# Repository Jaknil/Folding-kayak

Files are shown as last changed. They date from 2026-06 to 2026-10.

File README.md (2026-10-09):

# Folding-kayak

Build logs and instructions for making your folded origami kayaks from sheet of polypropylene plastic sheets. Original concept invented by [Aslag Guttormsgaard:](https://www.instagram.com/aslagsbrettekajakk/)

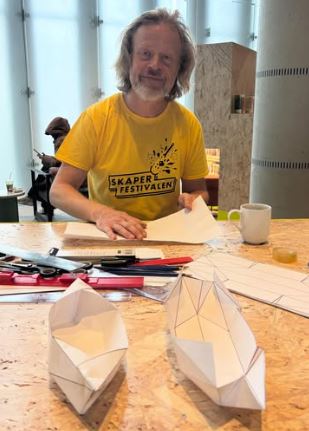
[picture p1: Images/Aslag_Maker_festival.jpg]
Aslag Guttormsgaard at Oslo Maker festival Deichman 2025, image from aslagsbrettekajakk on Instagram
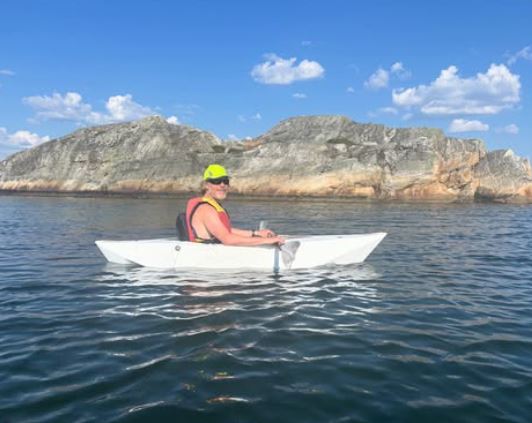
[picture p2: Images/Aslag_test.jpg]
Aslag Guttormsgaard on Koster, image from aslagsbrettekajakk on Instagram


# What is it?

A do it yourself kayak, made from a plastic sheet that is ultralight and packs up to a flat package. Read on to learn how.

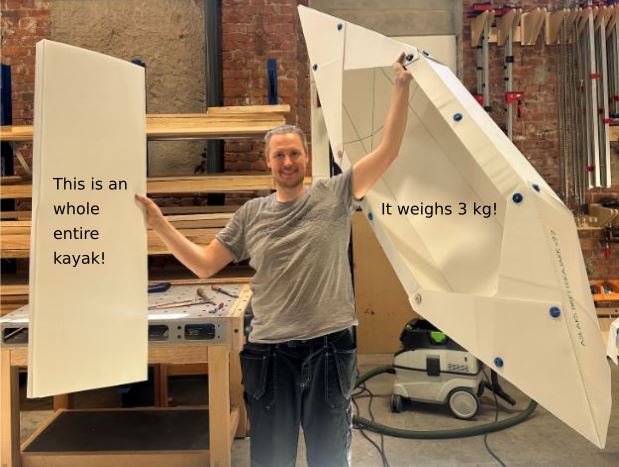
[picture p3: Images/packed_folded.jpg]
Jakob holding a packed and a folded kayak


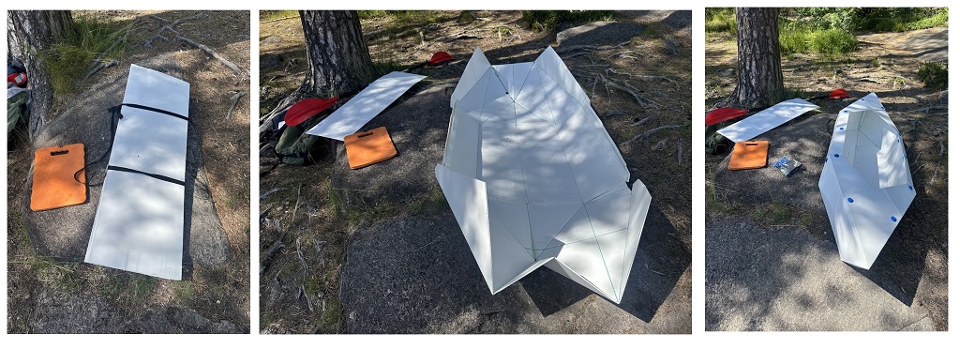
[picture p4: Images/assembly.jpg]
Assembly


It packs up to approximately 1220x500x50mm (left picture) and weighs 3kg total without paddles. Packing up or down took around 15 minutes each for my first time, [the inventor has the record with a 4 min assembly!](https://www.instagram.com/p/DQYdUIIiCEW/)

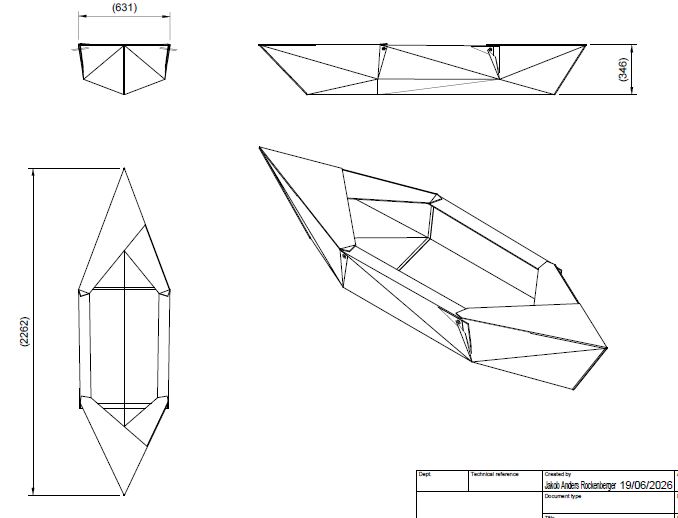
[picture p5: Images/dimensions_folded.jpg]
Dimensions folded


# But does it work?

Yes! We have made five thus far and tested them. The different versions have different quirks and fixes, see version log for details.

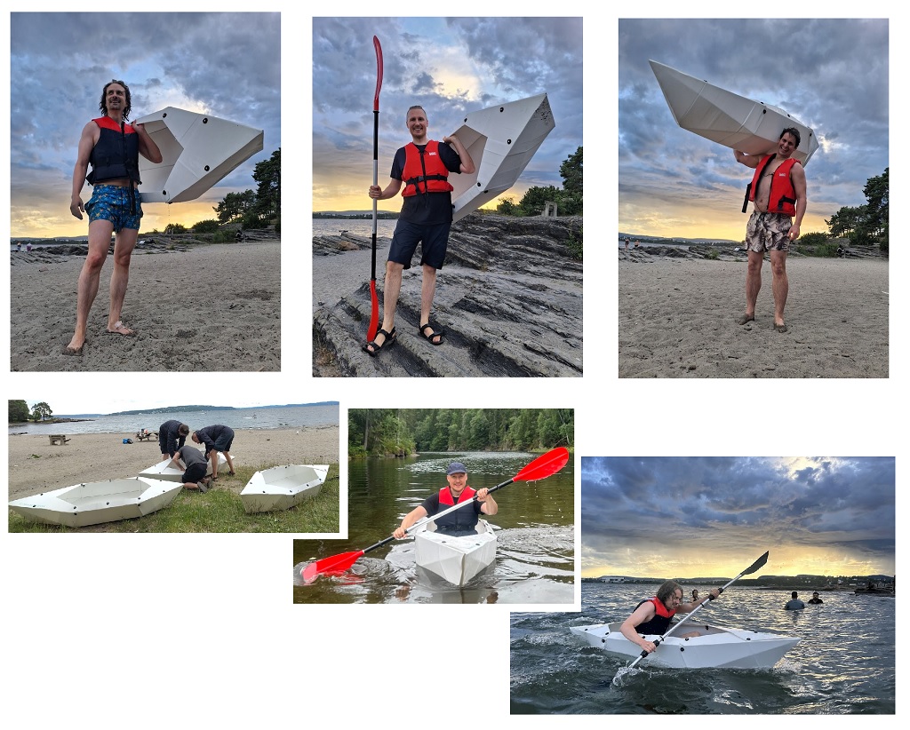
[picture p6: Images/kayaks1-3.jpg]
Testing the first three kayaks


Tests at Paradisbukta and Østmarka, Oslo 2026.

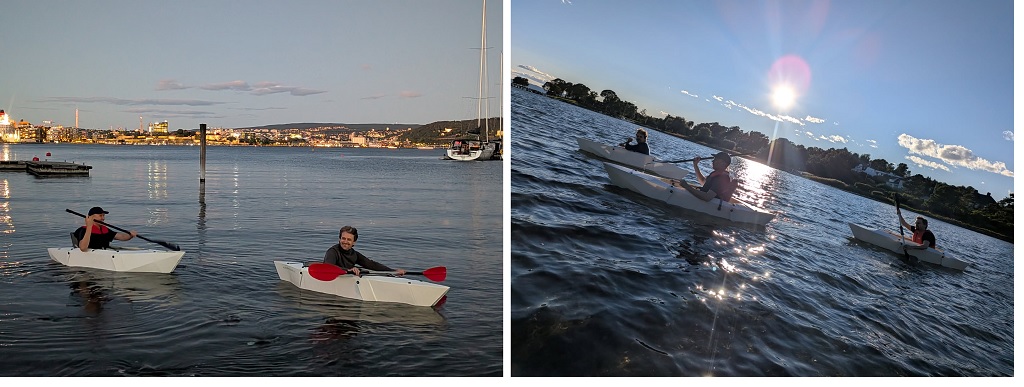
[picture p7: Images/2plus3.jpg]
Herbern trip


Restaurant trip to Lille Herbern, Oslo 2026.

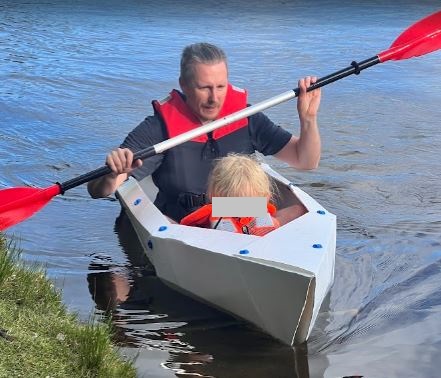
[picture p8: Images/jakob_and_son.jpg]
Father and son


1-2 kids on board as ballast has been found to improve stablity

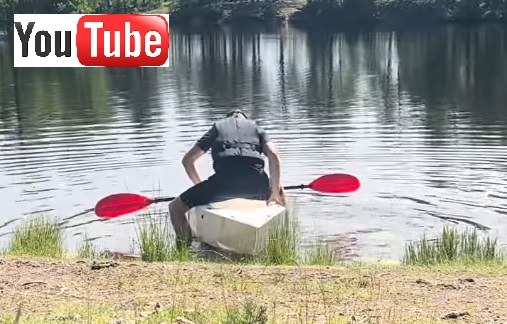
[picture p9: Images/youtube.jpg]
(https://youtu.be/oQs99TTAEPQ?si=FxAfOIfxH4dqbu4J)


[First test video on Youtube](https://youtu.be/oQs99TTAEPQ?si=FxAfOIfxH4dqbu4J)

## Who? Where?
We are a group of five Makers based in Oslo Norway attempting to make, improve and share Aslags fantastic kayak design! 

We are working out of the shared workshop [Fellesverkstedet](https://www.fellesverkstedet.no/) and they have been incredibly helpful in procuring the materials needed for the project. 

We are also making use of Norways biggest Makerspace: [Bitraf](https://bitraf.no/), for 3D -printing the fasteners.

### Production log 

We have made make 5 kayaks out of 8 sheets of polypropylene. Updated 09.102.2026

| Sheet | Use | Status |
| ----- | --- | --- |
| 1 |Seat for Kayak 1 + test| Done |
| 2 |Kayak 1 v2.2| Done |
| 3 |Kayak 2 v2.2| Done |
| 4 |Kayak 3 v2.2| Done |
| 5 |Kayak 4 v2.3| Done |
| 6 |Kayak 5 v2.3| Done |
| 7 |Seats for 2-3 v2.3| Done |
| 8 |Seats for 4-5 v2.3| Done |
| 9 | Spare| Planned autocrease experiment  |

Sheet 9 will be used to test the [autocreaser](autocreaser.md) 

## How to make folded kayaks

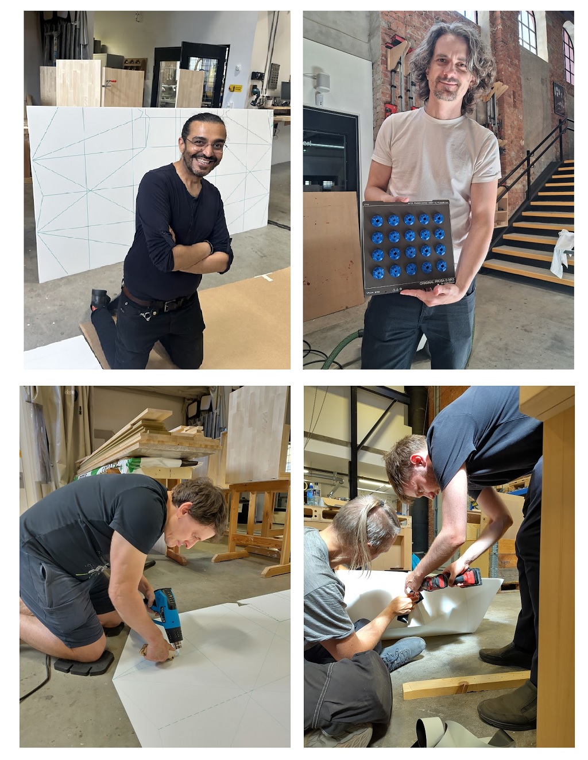
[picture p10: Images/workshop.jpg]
The crew working on version 2.2


### Bill of materials, per kayak:
- 1.5pcs of 2440mm x 1220mm fluted / internally corrugated polypropylene sheet - 4mm thickness 700g/m^2 - 1.5pcs / Kayakk ([Antalis supplier](https://www.antalis.no/eshop/medier-og-utstyr-for-visuell-kommunikasjon/plater/kanalplast-pp-pdp-hq08108/sku-694530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))
- 14pcs of M6 hex head screws 30mm length 
- 14pcs of M6 nuts
- Filament for 3D printing 28 lock washers (we used PLA) 
- Gaffa tape for temporary assembly

### Tools:
- 3D-printer for printing lock washers
- Exacto knife for cutting plastic
- A pen and a ruler or a large CNC for marking the sheets
- Hot air gun, preferably one that can be set to 150C
- Hand held roller, Ø5-10mm wide ca Ø30mm diameter. Can be laser cut, 3D-printed or made from scrap. [Rihno files](Lasercut-creasing-tool/CreasingToolv1.3dm)
- Handheld drill and a Ø6-7mm drill bit

### Methodology

Preparations:
1. 3D-Print all the lock washers (print a test one first)
2. Push the screws and nuts into the 3D-prints 

Making the Kayaks:
1. Find a large open space to work in. 4m x 2m minimum.
1. Mark where you want to cut and fold your sheet
1. [Cut the small pieces away](Images/cut.jpg)
2. [Heat the plastic locally to 150C using the hot air gun and](Images/crease.jpg)
3. [Create creases along the lines using a roller](Images/crease.jpg) 
4. Use a board or something stiff under the sheet when you first it, to help establish straight folds
5. [Youtube video: Shape the kayak and fix it in place using gaffa tape](https://youtube.com/shorts/2akg2EgOliQ)
6. Drill the holes for the screws
8. Use the screws and nuts with the 3D printed lock washers to assemble the whole kayak

# Research

- A sheet metal model was developed, see [tests for establishing k-value and new approximated sheetmetal model](sheet_metal_theory.md)
- An [auto-creasing tool](autocreaser.md) is being developed.
- Test alternative sheets designs to the channeled one

## Alternative sheet test

- [Akyprint smooth 3.3mm 900g/m from VINK](https://vink.no/media/import/NO_Akyprint_Brosjyre.pdf), works great in small scale test!

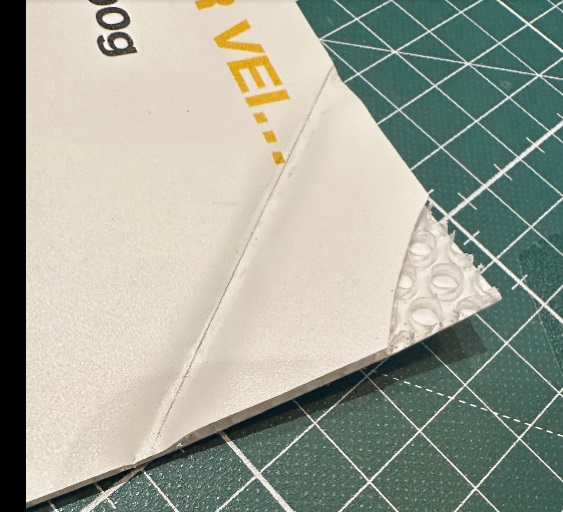
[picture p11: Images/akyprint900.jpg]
Standard heat crease and demo cut


[See autocreaser for more tests](autocreaser.md)

## Todo

- Test [autocreaser](autocreaser.md) in CNC
- Test out low seats with backs like [Falkeberg Ground Chair](./Images/ground_chair.JPG)
- Develop version 3.0 of the folding kayak 

## Version 3 - Under development

Change log
- Introduces more angles to the first pack up lines, makes a rounder more complex shape. 

Next step:
- Make new paper tests 

Only tested in paper.

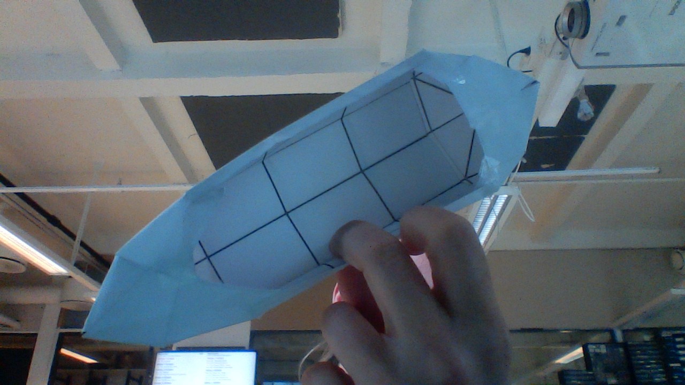
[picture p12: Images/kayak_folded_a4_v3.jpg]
Version 3 kayak


- [PDF drawing for A4 models](Drawings/V3_1Oct_double_top.pdf)

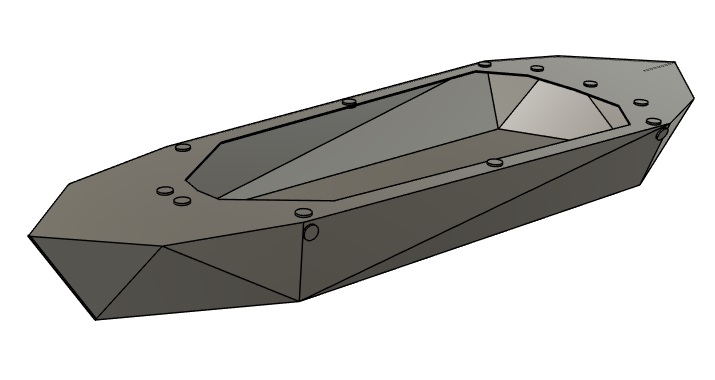
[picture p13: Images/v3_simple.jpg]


- [3D-model, web view](https://a360.co/4iS6Kz8) Including a comparison with v2 and a righting arm analysis setup

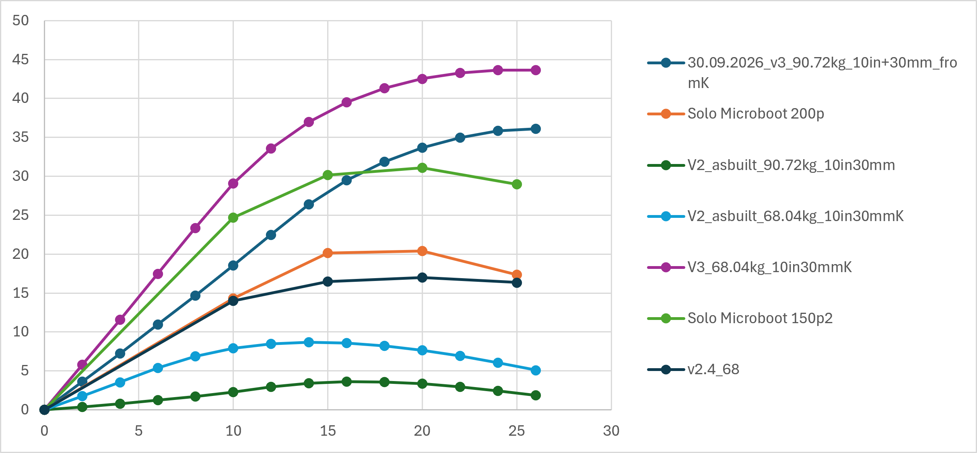
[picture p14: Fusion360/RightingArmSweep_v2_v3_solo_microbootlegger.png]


Righting arm vs Heel angle plot for different loads. Centre of gravity 254mm (10in = standard pilot assumption) + 30mm (assumed seat height) above keel.

- [Graph data CSV](Fusion360/TestData_v3_comp.csv)
- [Graph data Excel](Fusion360/RightingArmSweep_cleaned_plotted.xlsx)
- [Kayak stability therory](https://guillemot-kayaks.com/kayak-stability)
- [Solo Microbootlegger kayak](https://guillemot-kayaks.com/catalog/strip-built/recreational-kayak-solo/solo-microbootlegger) used as comparision

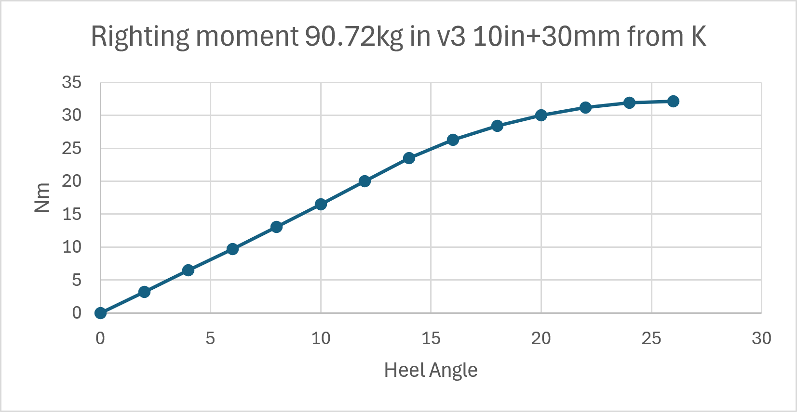
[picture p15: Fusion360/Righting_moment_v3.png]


- [DXF pattern](Drawings/Simple_pattern_v3_top_lines.dxf)

# Version history and test log

## Version 2.4

Not tested on paper, looks ok in old cad model that I don't trust completely.

[DXF for autocrease](Drawings/dxf-main_v2.4.dxf)

Remember to add double lines 6.7mm c-c for double folds!

Double crease all double folds:
- All pack up lines except the double ones in the middle
- All backside lines (4 flaps on sides and 2 on the points)
- Consider double folding armrests
- If time, test wider armrests

### Change log 
- The front is shorter to accomodate better pack up lines, also increases stability
- It's 50mm wider and 25mm lower than 2.3, making it more stable.

## Version 2.3

We made one or two of this main body but had seat inlays from v2.2, so no full v2.3 exist.

 These tweaks aim to stiffen the kayak further and avoid the innvards collapses. 
 
 - This update tries out several things, possibly overcomplicating the design. Some of these fixes might be enough on their own. 
 
### Change log 

- Extend the seat-inlay to use half a full sheet of polypropylene 1220X1220 = more bending, but creates lots more dimentions
- Move all the "pack up lines" to intersect with other lines. 
- Slope the cockpit sides innward to make the bends sharper in the nose and rear. This means cutting more from the corners, how much? Freehand? possibly not needed? Can we achieve the same thing some other way?

### Drawings

PDF in work!

[JPG Seat v2.3](./Drawings/seat_v2.3_tested.jpg)

[PDF Brettekajakk v2.3 pack_up lines only](./Drawings/Brettekajakk_pack_up_lines_v2.3.pdf)

[DXF seat v2.3](./Router-plot-DXF/Seat_v2.3_DXF.dxf) OBS! Error! one dimension is inncorrect. See JPG for correction

[DXF kayak main file v2.3](./Router-plot-DXF/Brettekayak_JR_v2.3.dxf)

### 3D-prints
- [1pcs-Lock-washers-folding-kayak-M6-Screw-holder.3mf](3D-print-3MF/1pcs-Lock-washers-folding-kayak-M6-Screw-holder.3mf)
- [28pcs-Lock-washers-folding-kayak-M6-Screw-holder.3mf](3D-print-3MF/28pcs-Lock-washers-folding-kayak-M6-Screw-holder.3mf)

## Version 2.25

This is using a v2.2 kayak main body and a v2.3 seat inlay.

### Test results and impressions

- The seat inlay v2.3 was a success! It stopped most of the inversions that v.2.2 suffered from. We don't know if this more complicated seat is strictly neccessary for version 2.3 kayaks but it gives more strength than 2.2 so it doesn't hurt.
- The ergonomics is still somewhat lacking. A backrest would be very nice for any longer trips. We have not tested the beach chair solution yet.
- The sides are rather high and wide, they can be pulled in front of the pilot to give better room to paddle. 
- The pilot has to sit almost in the very middle of the kayak with their feet in the tip for the kayak to float level in the water. There is room for improvement! We consider a more almond shaped design for version 3.0 with a wider back and narrow front. 
- [We have taped up the open edges of the sheet with silver-tape.](Images/taped.jpg) It can give it around 10 liters of trapped air for lift in an emergency and reduce cuts and scrapes. Especially on the sides of the cockpit.

## Version 2.2

### Test results and impressions

June 22 2026 - Jakob Rockenberger at Vesletjern

 It handles OK. Not fast not very rank or very stable. Tracks fine, not very fast. Survived some banging and grinding on rocks. Since it lacks sealed air chambers it's not something I'd risk the open seas with, but prefect for exploring a lake or a creek where you can swim to shore if you need it. The main advantage is that you can easily pack it up and take a bus home afterwards. I weigh 75kg and paddled easily around a small lake together with my 5 year old! 
 
 I sat on a foam mat with a rolled up towel underneath to let the boat keep the V shape in the bottom. We can possibly make a triangle from leftover material that we can use instead if we have enough. 

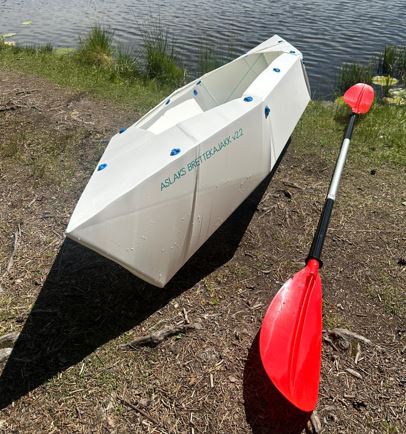
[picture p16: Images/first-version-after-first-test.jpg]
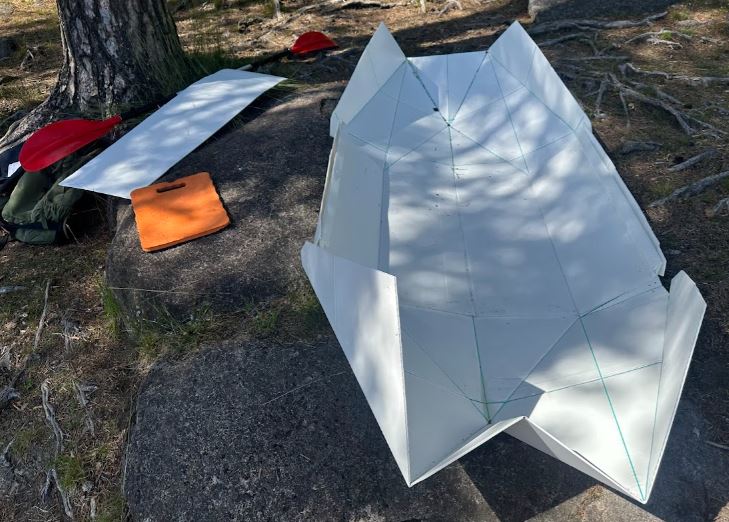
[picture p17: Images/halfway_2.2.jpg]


#### Inversions

- The kayak experienced some innvards local "collapses" of the shape of the Kayak, surfaces that should be convex became concave, when they were pushed in by the water-pressure. This happend in the bottom area under my calves and behind me from both sides. 
- Note that the kayak didn't become unsafe when this happened! When the bottom front inverted, the sideways stabiliy increased as well as the drag. I didn't notice the rear inverting until later, but I assume I lost some boyancy, forcing me to sit more to the front
- I think the reasons was the "pack up" folds, in this version they didn't intersect existing geometry. This can easily be changed in next version.
- Two more kayaks has already been creased with these unfortunate "pack up" folds, and we want to finish them regardless.
- Several potential fixes will be tested in version 2.3. 

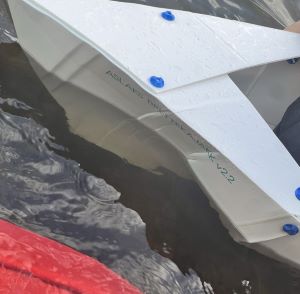
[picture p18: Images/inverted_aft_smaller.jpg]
Aft inversion


### Change log and notes

- The drawings now include previously missing and corrected dimesions for how much to cut off the corners.
- Bend lines for packing up (missing from the PDF drawing) are placed such a way in the DXF that it folds nice and small, around 400mm wide package.
- The bend lines for packing up appear to make it weaker. Consider moving them to natural intersection-points. 
- Was assembled and tested with vertical sides to the cockpit, it is possible that it would be stronger if they were curved in a bit. Intended in v2 original design?

### Drawings 

This is the drawing for our version 2.3. based on a model recreated in Fusion360 by Jakob from Aslags drawings. 

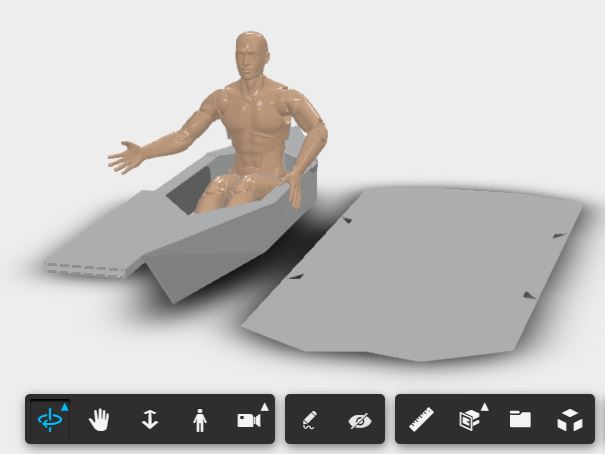
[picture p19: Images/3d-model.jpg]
Interactive 3D-model of the v2.2 kayakk (https://a360.co/4fWsus3)


[*Interactive 3d-model of the kayakk*](https://a360.co/4fWsus3)

[PDF Drawing for version 2.2, without "pack up lines"](./Drawings/Drawing_v2.2.pdf)

[DXF version, with "pack up bend lines"](./Router-plot-DXF/Brettekayak_JR_v2.2.dxf)

## Folding Kayak Aslagstyle - Brettekajakk Aslagstyle v1.0 and V2.0
Invented by [Aslag Guttormsgaard](https://www.instagram.com/aslagsbrettekajakk/) and shared with the public at [Oslo Skaperfestival 25. - 26. oktober 2025](https://deichman.no/aktuelt/oslo-skaperfestival-2025_D67nCl3o7T) ([Alt. link](https://skaperfestivalen.no/)). Attendies could fold their own mini kayaks from printouts on A4 paper. Aslag exibited his model 1 and 2 at the festival.

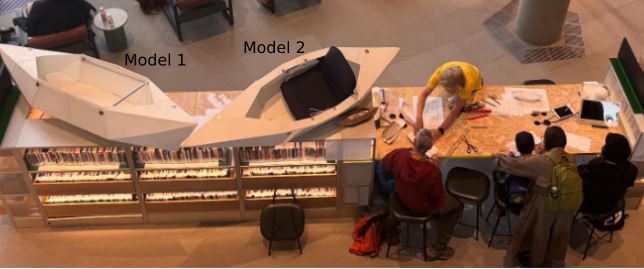
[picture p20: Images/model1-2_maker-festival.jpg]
Model 1 and 2 at the Oslo Maker festival in 2025


### Drawings 

#### Version 2.0 

This is the drawing for version 2.0. Changes from the previous version is that it has the added railing to rest your hands on. Don't mind that the text in the drawing says model 3.

[Drawing for version 2.0](./Drawings/Aslag_Kajakk_modell_2.pdf) "MODELL 3"

#### Version 1.0 

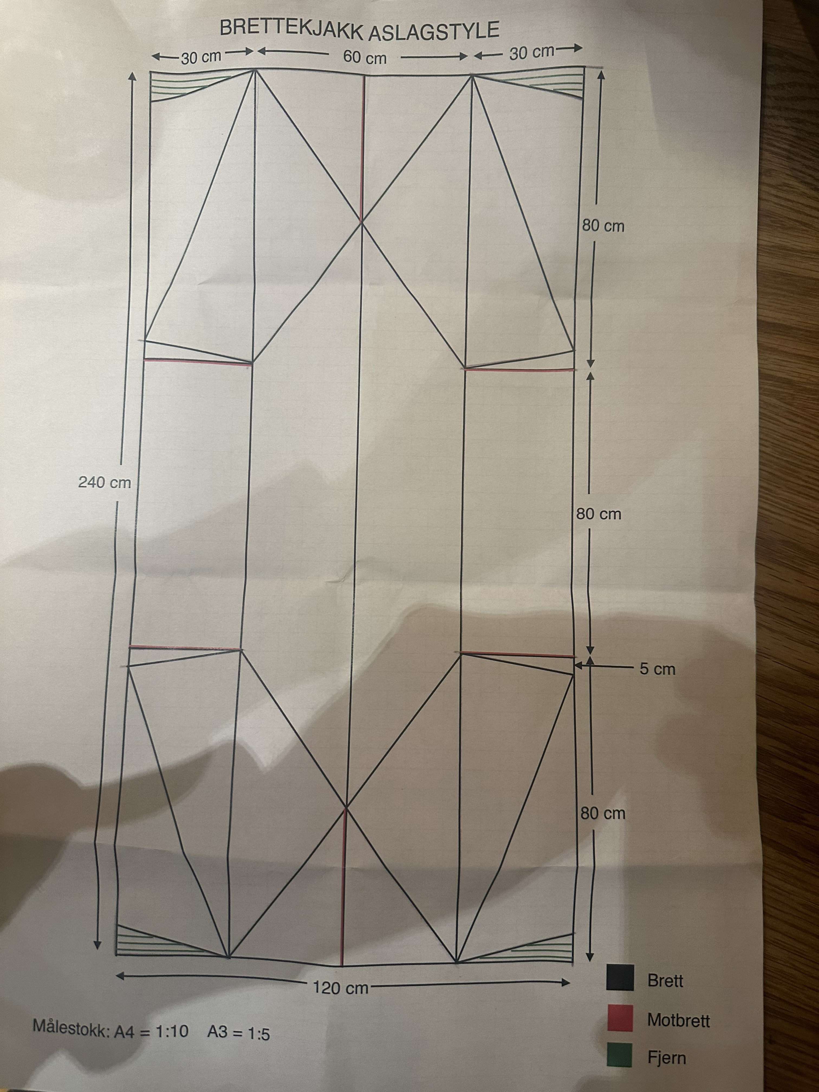
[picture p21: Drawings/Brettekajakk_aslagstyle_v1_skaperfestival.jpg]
Paper handout of version 1.0 from Oslo Maker Festival


Paper handout of version 1.0 from Oslo Maker Festival

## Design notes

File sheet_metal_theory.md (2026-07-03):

# Sheet metal approximation of corrugated plastic sheet in Fusion360

### Motivation
We wanted a more robust way to quickly visualise and generate "correct enough" drawings for new designs of the [folding kayaks.](./README.md)

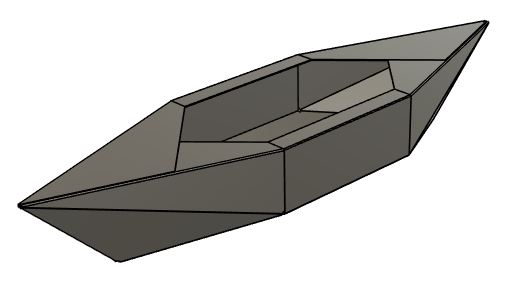
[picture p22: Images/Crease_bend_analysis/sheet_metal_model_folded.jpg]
Sheet metal model of kayak


[*Link to Sheet metal model of kayak in Fusion 360*](https://a360.co/3T9g3j9)

### Results

Our investigations indicate that these were good enough values:

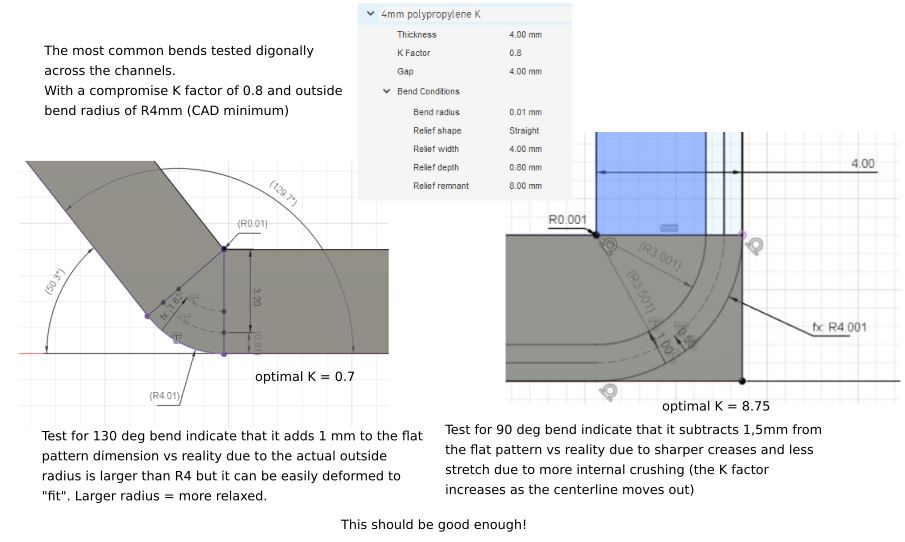
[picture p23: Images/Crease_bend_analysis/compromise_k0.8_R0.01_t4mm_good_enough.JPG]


* K factor = 0.8
* Internal radius = 0.01
* Material thickness = 4
* External radius = 4.01

### Modeling stategy

1. Make 2D sketches defining all critical corners of a quarter of your kayak.
2. Patch them to a surface model, stitch together
3. Make a relief cut at all bend intersections. Revolve a half circle to cut with a sphere.
3. Add the internal radius to all bends
4. Thicken to a solid model
5. Convert the solid model to Sheet metal
6. Unfold and all bends, this adds them to the sheet metal model
7. Add and trim so that the unfolded model respects the sheet boundary
8. Refold
7. Generate flat pattern

Notes:

* Fusion doesn't like the 0.01 internal radius. A larger internal radius = more stable model, but will be less accurate.
* Break down the kayak into quarters for a more stable model. You can extrapolate the last bits.

## Folds to Bends theory

We know that the plastic sheet does not bend as a metal sheet does. The aim here is to find values that take us close enough.

### Metal sheet bending theory:

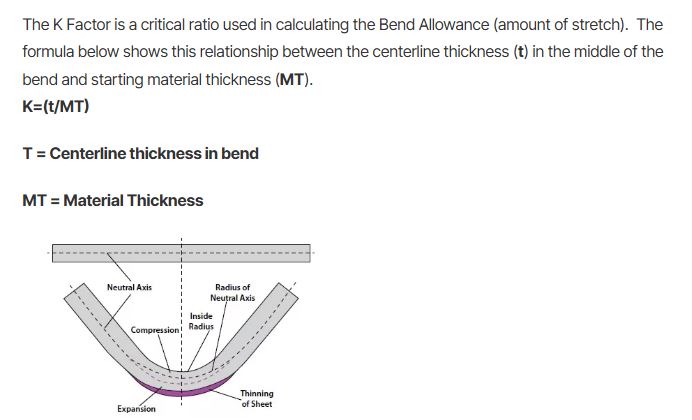
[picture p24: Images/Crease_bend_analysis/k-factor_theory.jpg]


[Image from sendcutsend.com](https://sendcutsend.com/blog/what-is-k-factor-in-bending-terminology/).

### Plastic sheet bending experiments

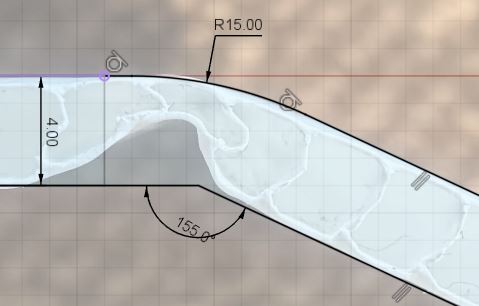
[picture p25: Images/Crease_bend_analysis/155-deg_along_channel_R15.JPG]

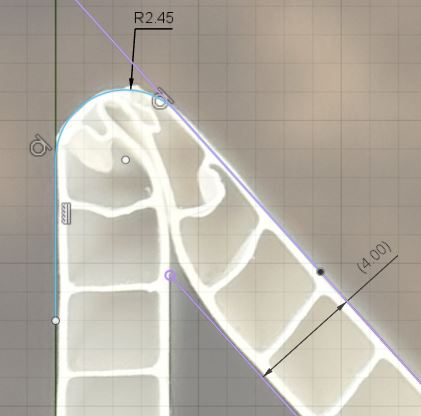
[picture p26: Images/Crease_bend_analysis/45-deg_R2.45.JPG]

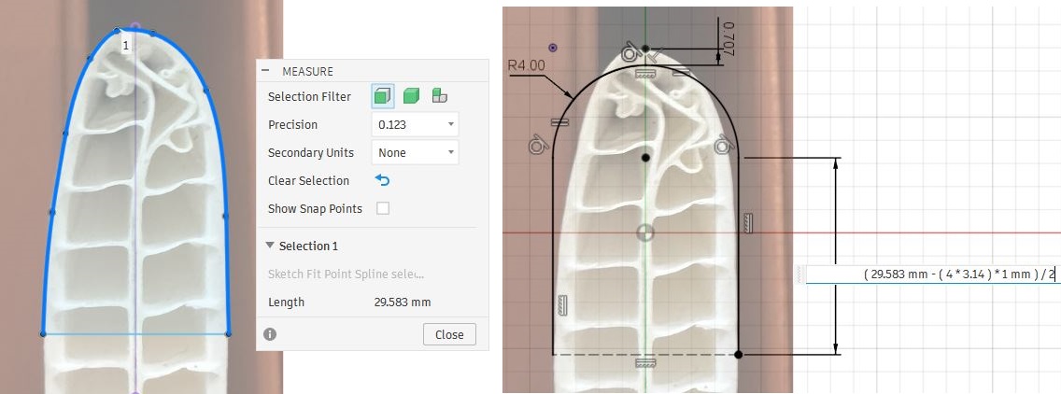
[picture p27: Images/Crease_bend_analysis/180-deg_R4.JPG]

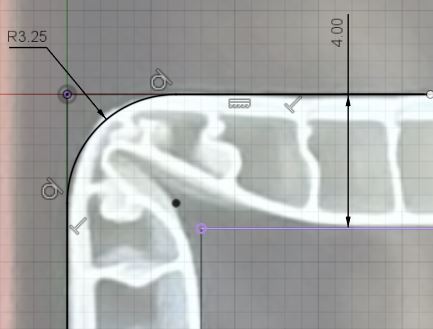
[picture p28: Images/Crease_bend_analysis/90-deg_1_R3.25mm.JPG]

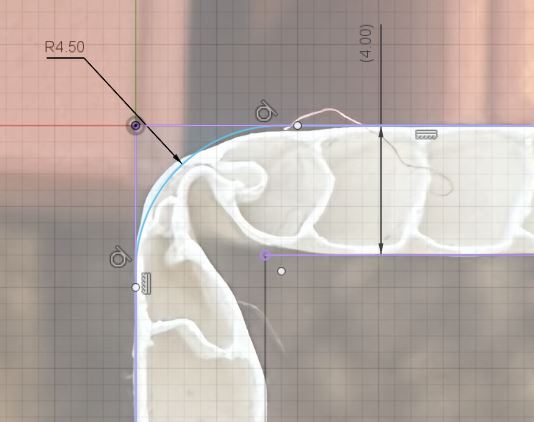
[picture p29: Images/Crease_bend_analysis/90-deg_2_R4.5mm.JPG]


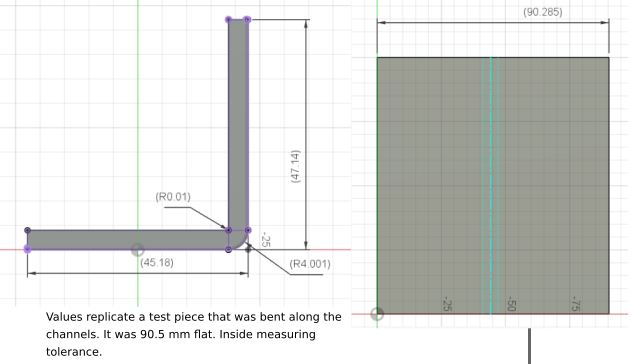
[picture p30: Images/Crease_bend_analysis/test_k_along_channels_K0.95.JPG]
Along channels

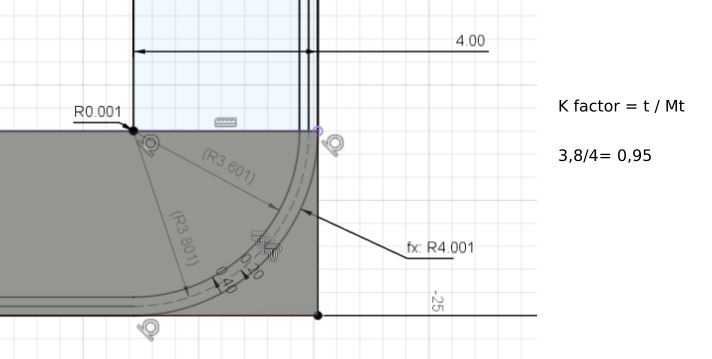
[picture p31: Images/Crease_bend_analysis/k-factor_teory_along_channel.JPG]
Along channels


Bends along the channel should use even higher k factors. Here is a test which indicate k factor =0,95 would worsk for 90 deg bends made along the channels.

#### Observations and conclusions

* Sharper folds = sharper outside radius. Past the point of what is possible to simulate with sheet metal. Meaning we will use the smallest possible inside radius to get as close as we can.
* The K-factor varies with how deep the inside layer crushes into the fold, which is dependent on fold sharpness and channel angle. In the end I had to pick something represenatative.
* Further testing, to be scientific, would be showing "the negative" what happens when the k-faktor/radius is wrong, how bad does it get?
* But this should be enough to move forward with.

### Material properties

The kayaks are built from thin sheets of polypropylene. 

- 4 mm thick plates
- Channels with square cross-sections
- Approximate 0.2mm actual material thickness around and between channels

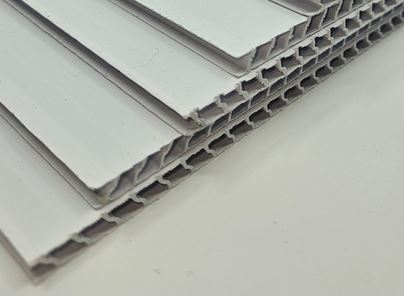
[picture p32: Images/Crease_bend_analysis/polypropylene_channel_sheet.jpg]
Plates (https://www.antalis.no/eshop/medier-og-utstyr-for-visuell-kommunikasjon/plater/kanalplast/kanalplast-pp/pdp-hq08108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)


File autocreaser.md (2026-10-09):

# Autocreaser for folding kayaks

The goal is to be able to use a large CNC machine to automate the creasing of polypropylene sheets when [folding kayaks.](./README.md)

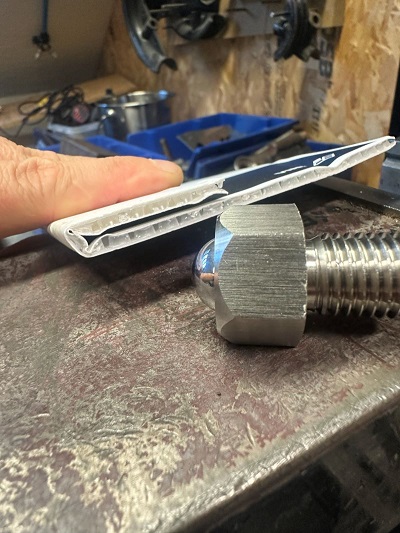
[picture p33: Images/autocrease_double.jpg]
Successful autocrease test, linear 1 axis


Successfull test at [Bitraf](https://bitraf.no/)!

Sheet used: [Akyprint smooth 3.3mm 900g/m from VINK](https://vink.no/media/import/NO_Akyprint_Brosjyre.pdf) with a Ø16mm free rolling ball driven at a fixed height, no heat needed.

Verified double crease line center-center spacing 6.7mm with a 3.3 mm thich sheet. Gives better result than the picture above.

[Youtube short, autocrease test](https://youtube.com/shorts/zlMBDUQS9Cw)

## BOM
- Adapter for creasing ball [Fusion360](https://a360.co/4yF22JU) or [STL-file for printing](3D-print-STL/Adapter.stl)

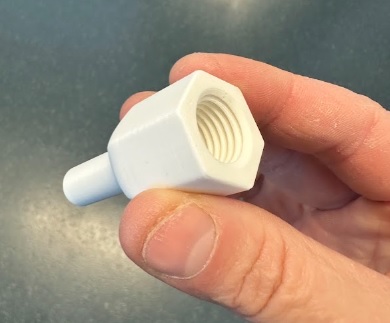
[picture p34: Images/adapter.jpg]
Adapter


The 3D-printed Ø12mm adapter can act as a break-away if we have ha catastrophic collison.

- Conveyor Ball Roller QB312, M16 from [Aliexpress](https://www.aliexpress.com/item/1005005415776359.html)

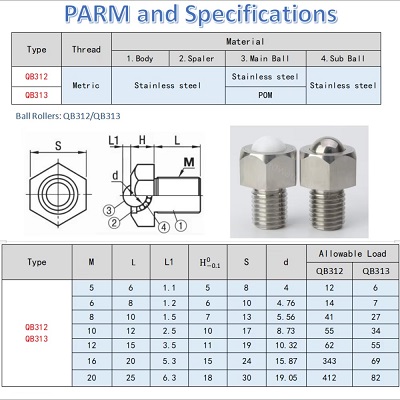
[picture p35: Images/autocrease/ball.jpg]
ball size


## Working principle 

- Mount Ø16mm ball with Ø12mm adapter in spindle collet on shopbot CNC
- Fix the sheet with tape
- Adjust the Z-offset to control the pressure on the sheet
- Crease one side at a time

## First prototype

The spring pin was not smooth enought when exposed to sideways forces.

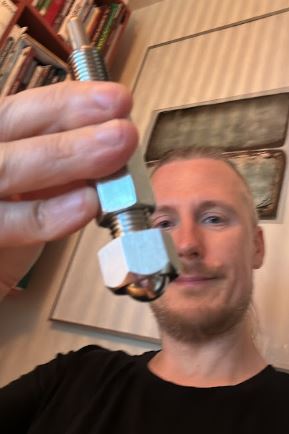
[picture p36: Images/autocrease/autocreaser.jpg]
First prototype


- Ø8mm Steel spring pin QB515-SH, M16 from [Aliexpress](https://www.aliexpress.com/item/1005006329455989.html)

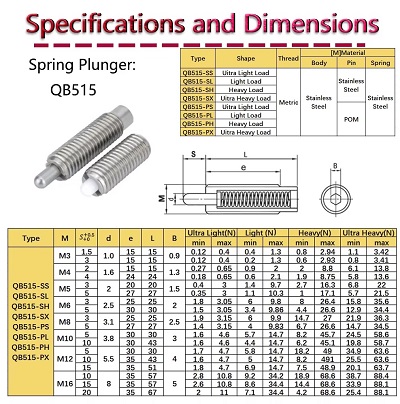
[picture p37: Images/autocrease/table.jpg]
Spring pin force


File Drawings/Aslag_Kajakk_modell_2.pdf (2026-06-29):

## MODELL 3 Inneplate 80x 106

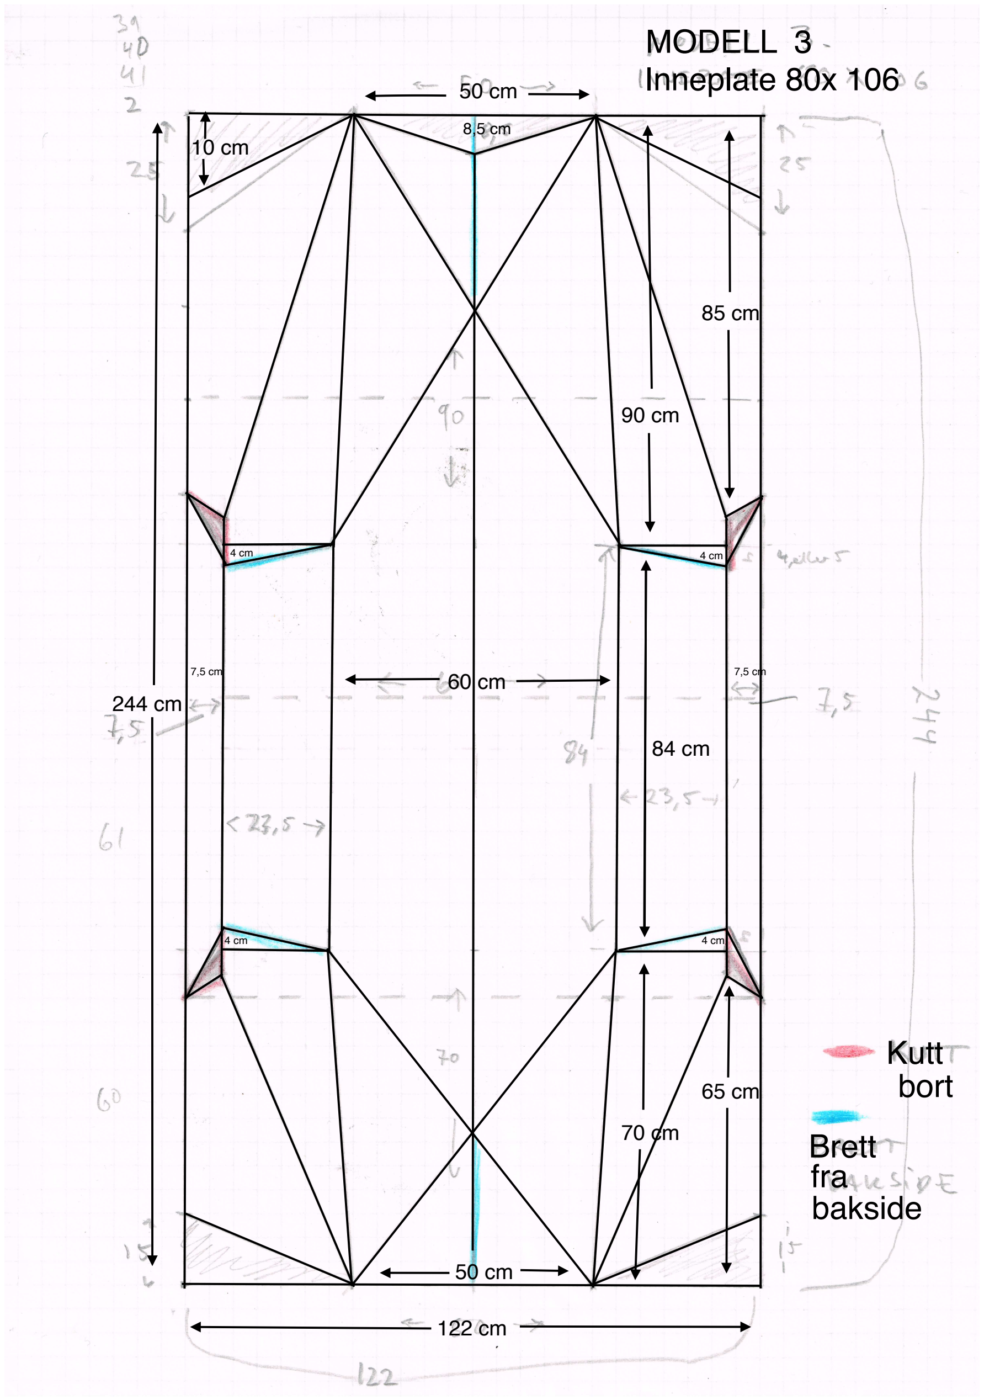
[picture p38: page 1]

84 cm

244 cm

122 cm

## Kutt

50 cm

50 cm

## Brett

7,5 cm

## fra

70 cm

90 cm

4 cm | 4 cm

65 cm

85 cm

## bort

4 cm | 4 cm

7,5 cm

8,5 cm

## bakside

60 cm

10 cm

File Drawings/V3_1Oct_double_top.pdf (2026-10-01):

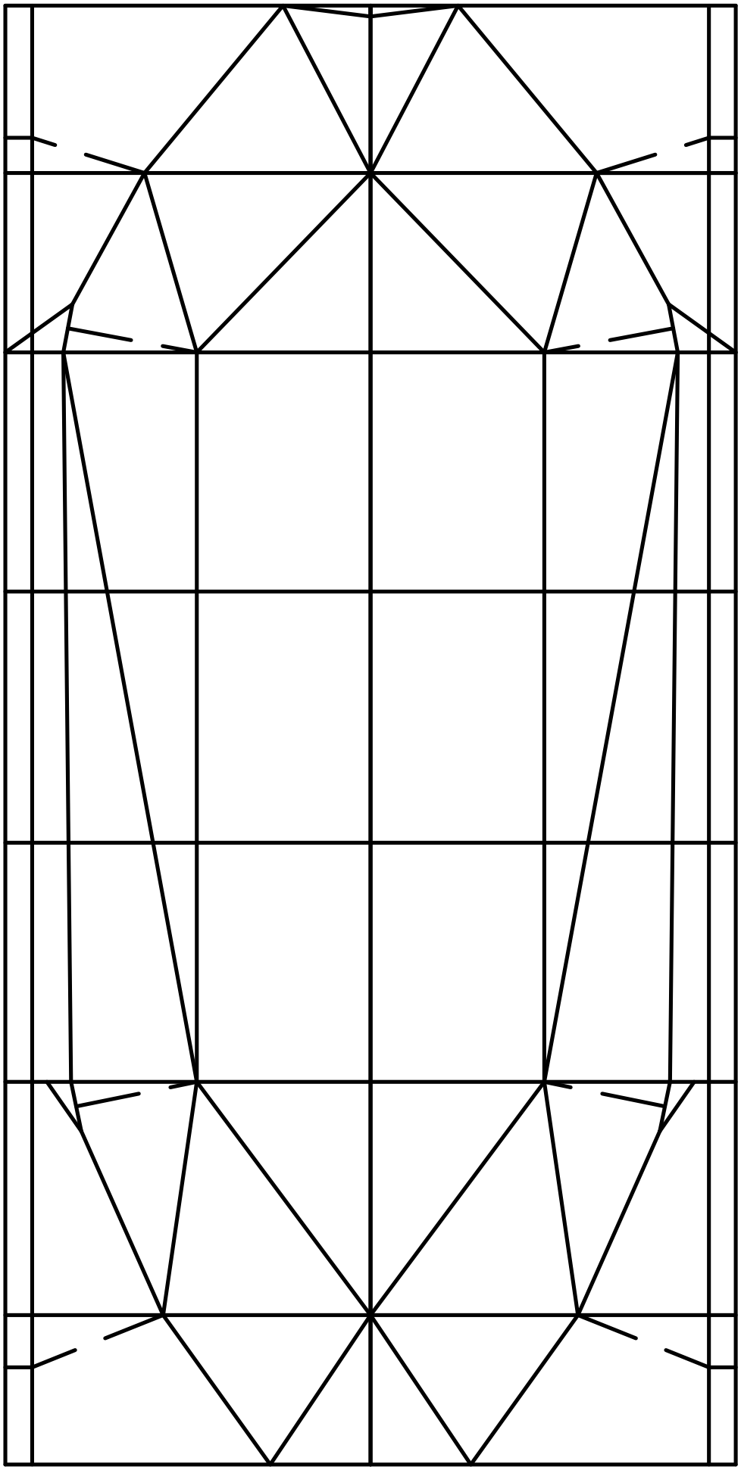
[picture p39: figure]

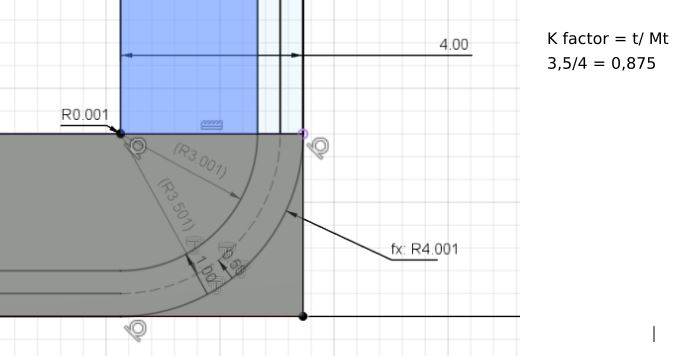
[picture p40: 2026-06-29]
Images/Crease_bend_analysis/k factor - diag alternative_channel-theory_k0.875.JPG

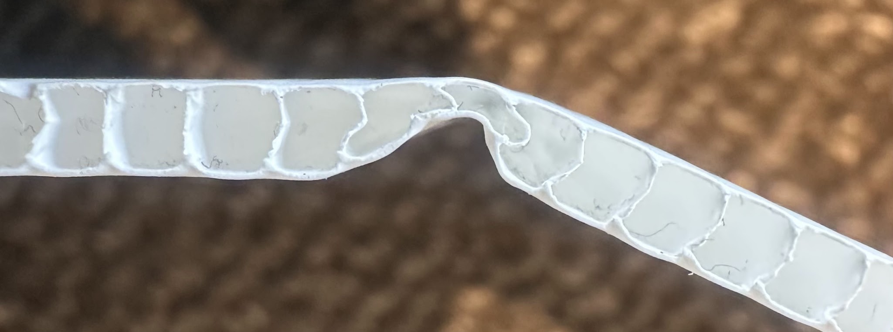
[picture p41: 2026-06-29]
Images/Crease_bend_analysis/155-deg_1.jpg

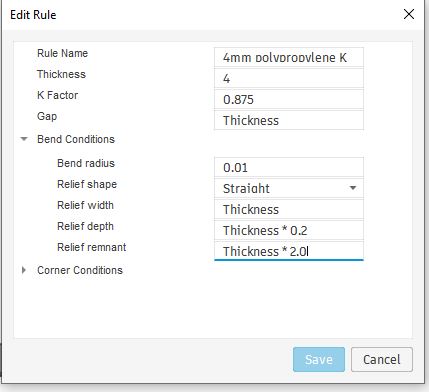
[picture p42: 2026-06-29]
Images/Crease_bend_analysis/k-factor-diag_alt-settings_window_k0.875.JPG

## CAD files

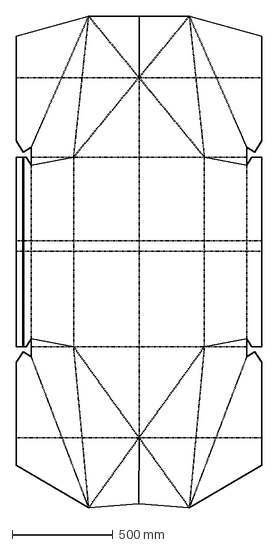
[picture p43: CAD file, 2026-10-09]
Drawings/dxf-main_v2.4_railing.dxf
1220.0 x 2440.0 mm

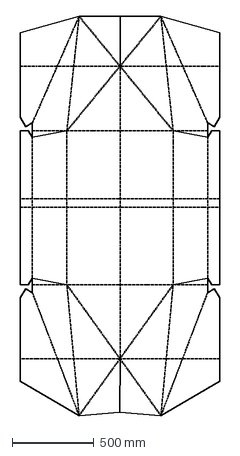
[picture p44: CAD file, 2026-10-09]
Drawings/dxf-main_v2.4.dxf
1220.0 x 2440.0 mm

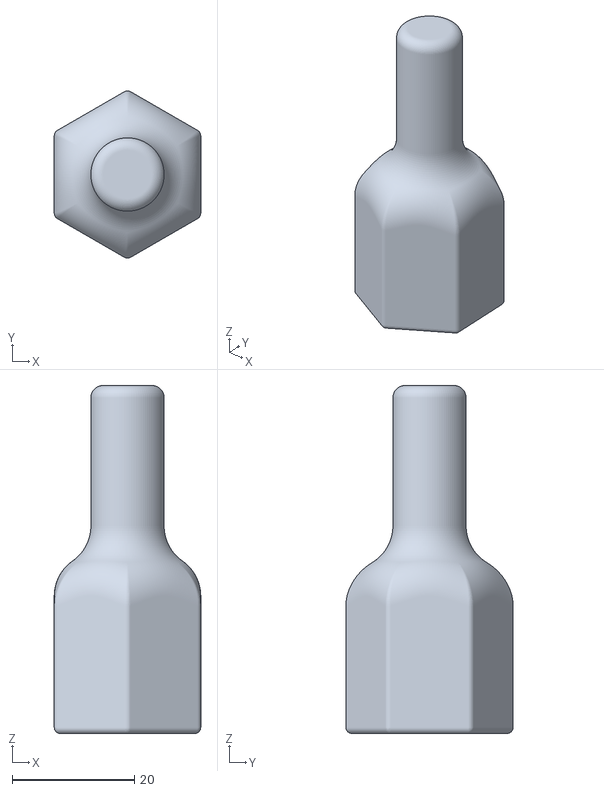
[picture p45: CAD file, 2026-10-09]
3D-print-STL/Adapter.stl
24.0 x 27.4 x 57.0

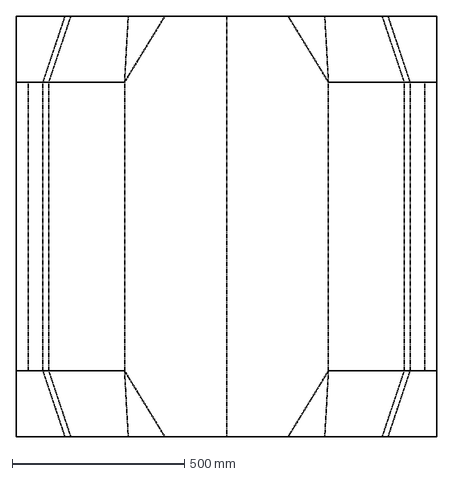
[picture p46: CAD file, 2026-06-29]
Router-plot-DXF/Seat_v2.3_DXF.dxf
1220.0 x 1220.0 mm

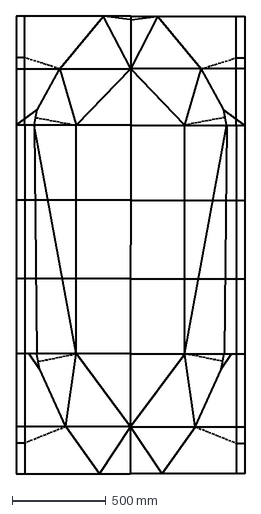
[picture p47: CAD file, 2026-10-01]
Drawings/Simple_pattern_v3_top_lines.dxf
1220.0 x 2440.0 mm

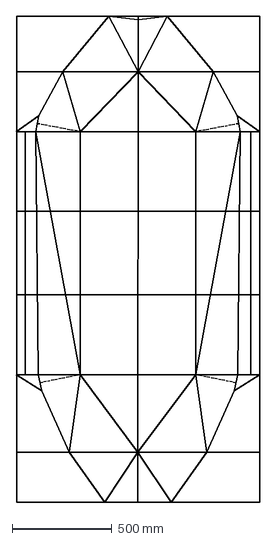
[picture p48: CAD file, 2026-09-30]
Drawings/#Simple_pattern_v3_both_sides.dxf
1220.0 x 2440.0 mm

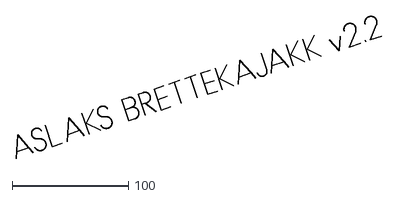
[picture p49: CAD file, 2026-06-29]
Router-plot-DXF/Marker plot - side2 - name.dxf
314.9 x 122.6

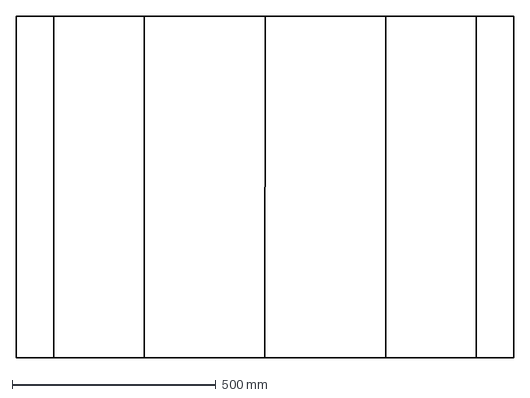
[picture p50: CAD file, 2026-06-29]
Router-plot-DXF/DXF_Seat_reinforce_JR_v2.2.dxf
1220.0 x 838.0 mm

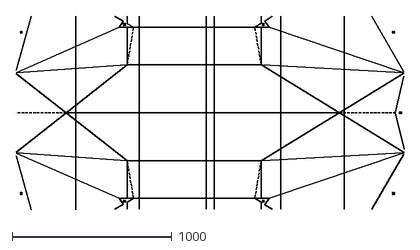
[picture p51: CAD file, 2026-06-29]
Router-plot-DXF/Marker plot - side1 - lines.dxf
2431.8 x 1212.0

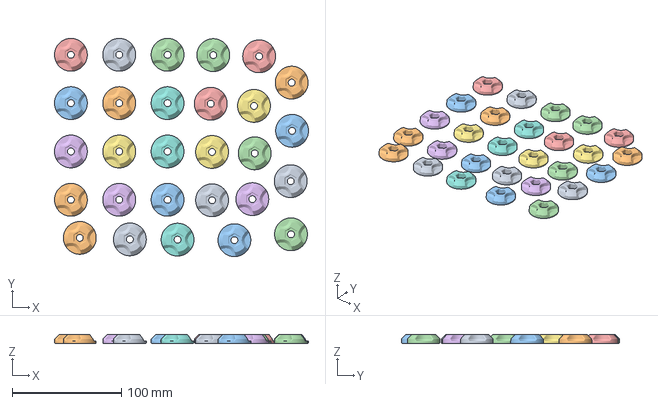
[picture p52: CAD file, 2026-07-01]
3D-print-3MF/28pcs-Lock-washers-folding-kayak-M6-Screw-holder.3mf
232.1 x 199.4 x 8.00 mm

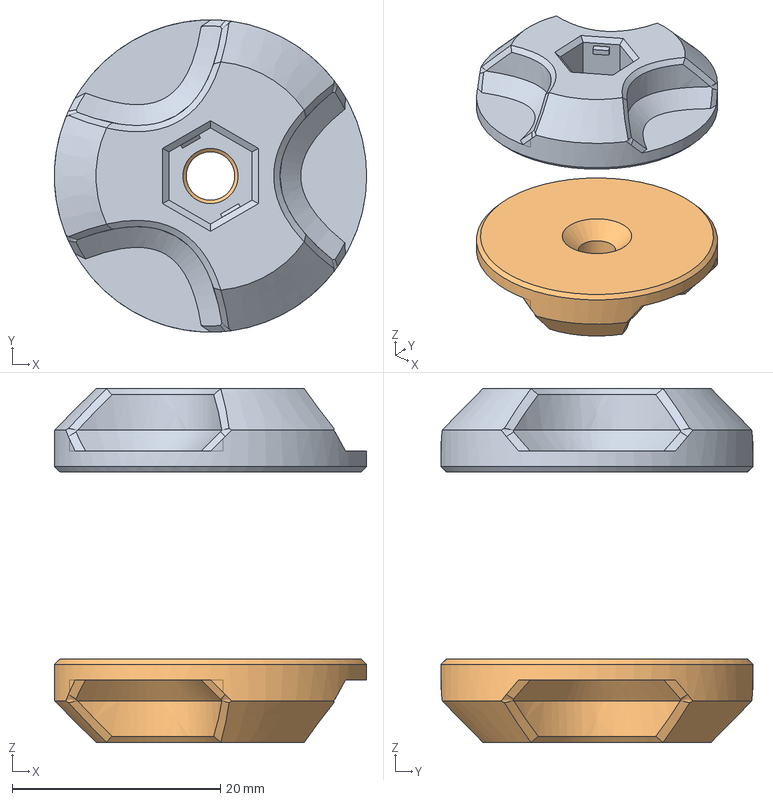
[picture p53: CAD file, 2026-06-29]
FreeCAD-files/Lock-washers-folding-kayak.FCStd
30.0 x 30.0 x 34.0 mm
Screw-holder
Nut

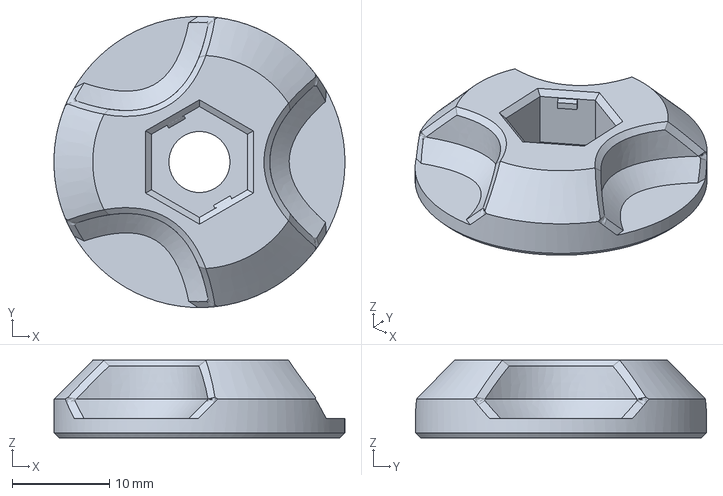
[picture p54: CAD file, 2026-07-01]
3D-print-3MF/1pcs-Lock-washers-folding-kayak-M6-Screw-holder.3mf
30.0 x 30.0 x 8.00 mm

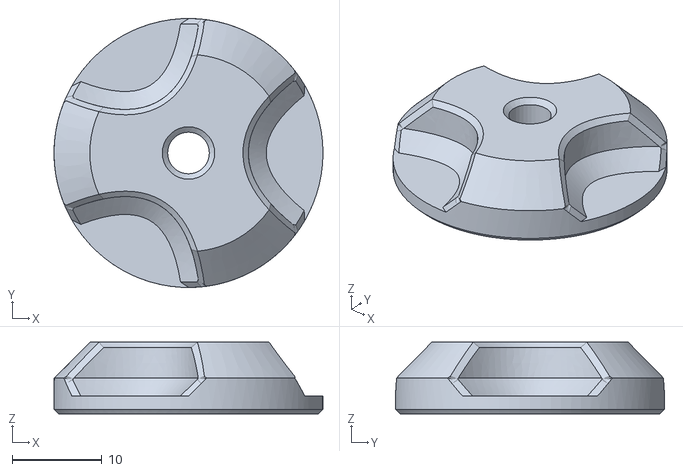
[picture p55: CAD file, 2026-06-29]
3D-print-STL/Lock-washer-v1-Nut.stl
30.0 x 30.0 x 8.00

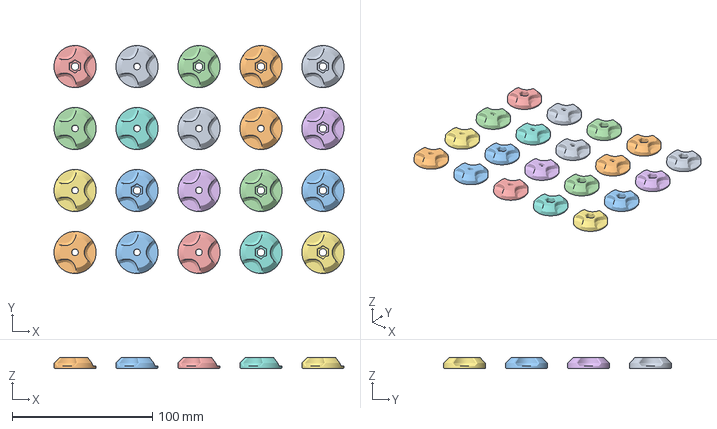
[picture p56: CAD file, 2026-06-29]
3D-print-3MF/10pcs-lock-washers.3mf
206.7 x 162.5 x 8.00 mm
Låsekskiver-brettekajakk-v1-Nut.stl
Låsekskiver-brettekajakk-v1-Screw-holder.stl

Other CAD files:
Router-plot-DXF/#Brettekayak_JR_v2.3.dxf
3D-print-STL/Lock-washer-v1-Screw-holder.stl
3D-print-3MF/Lock-washers.3mf
Router-plot-DXF/Brettekayak_JR_v2.2.dxf
BarkBeetle-CAM/Folding kayak - BarkBeetle.3dm
Lasercut-creasing-tool/CreasingToolv1.3dm
Router-plot-DXF/Brettekayak_JR_v2.3.dxf

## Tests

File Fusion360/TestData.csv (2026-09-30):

HeelAngle | Run 1 | Run 1 (2) | Right_way | Alltheway
0.0 | -1.1338100201744642e-13 | 0.0 | -5.668562935685469e-14 | 5.669433454484708e-14
2.0 |  |  |  | 4.274925142964548
3.0 | -6.417942255765436 | -6.417945470028437 | 6.418054768964026
4.0 |  |  |  | 8.578860087347621
6.0 | -12.959770910446986 | -12.959770859456135 | 12.960484399035607 | 12.96040166038281
8.0 |  |  |  | 17.453897586483855
9.0 | -19.75334234644901 | -19.75334234644901 | 19.755139287246834
10.0 |  |  |  | 22.098927882302824
12.0 | -26.860368806477616 | -26.860368806477616 | 26.867564770456337 | 26.86667757865107
14.0 |  |  |  | 30.889731714584023
15.0 | -32.56939291439672 | -32.56939291439672 | 32.57233983344344
16.0 |  |  |  | 34.078777623654766
18.0 | -36.5574871921707 | -36.5574871921707 | 36.55890254335075 | 36.558729850757615
20.0 |  |  |  | 38.5060806030052
21.0 | -39.30589573386138 | -39.30589573386138 | 39.30984694924404
22.0 |  |  |  | 40.0156857328863
24.0 |  |  |  | 41.18092733887934
26.0 |  |  |  | 42.061772404469046

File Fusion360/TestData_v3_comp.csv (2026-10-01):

HeelAngle | 30.09.2026_v3_90.72kg_10in+30mm_fromK | Solo microbootlegger w 90.72kg 10 in ab seat | V2_asbuilt_90.72kg_10in30mm | V2_asbuilt_68.04kg_10in30mmK | V3_68.04kg_10in30mmK | Solo Microboot | jens
0.0 | -1.05E-13 | 0 | -5.13E-14 | -1.37E-13 | -1.91E-14 | 0 | -5.3290705182007514e-14
2.0 | 3.6143025886678917 |  | 0.3821508645785543 | 1.7582880946499835 | 5.776778969584809 |  | 5.2887641053628265
4.0 | 7.251561007843408 |  | 0.7798108889759936 | 3.535706804022851 | 11.579616759976219 |  | 10.602958636277659
6.0 | 10.934704290814638 |  | 1.2187317545644927 | 5.350797616327929 | 17.43444212378887 |  | 15.967930378938206
8.0 | 14.686685862088291 |  | 1.716261000807009 | 6.888213104 | 23.36719981452537 |  | 21.409031869086036
10.0 | 18.53046568423254 | 16.1544 | 2.2913956700277627 | 7.902710711385819 | 29.088222431856853 | 24.6888 | 26.900925091450713
12.0 | 22.48893704474127 |  | 2.9542475405742596 | 8.477257262144748 | 33.566160253357296 |  | 31.478243566656083
14.0 | 26.386600348392697 |  | 3.431615646143893 | 8.682122664282952 | 36.96804484 |  | 34.97197814222415
15.0 |  | 20.1168 |  |  |  | 30.1752
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

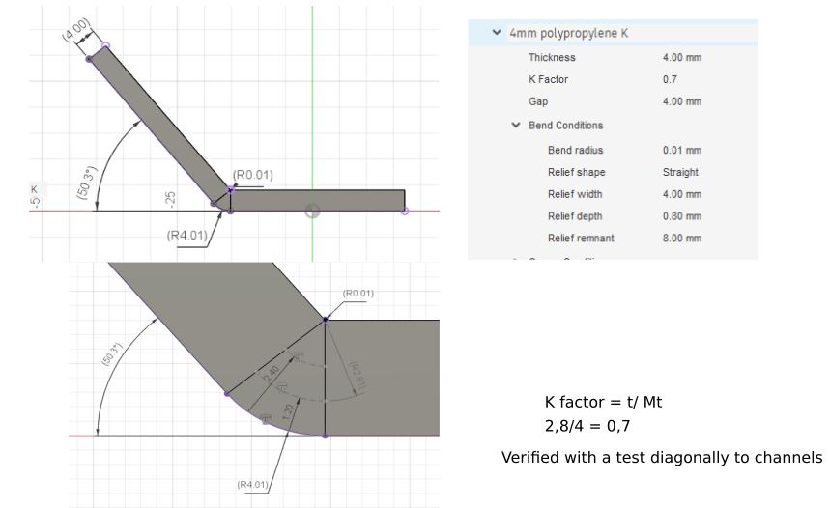
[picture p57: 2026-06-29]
Images/Crease_bend_analysis/130_deg-theory_and_test_k0.7.JPG

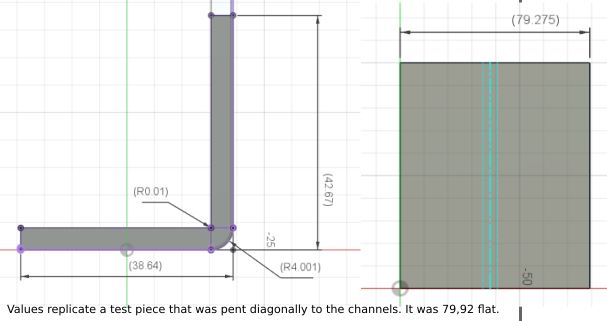
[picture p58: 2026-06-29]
Images/Crease_bend_analysis/k-factor_test-90-deg_diag_K0.95.JPG

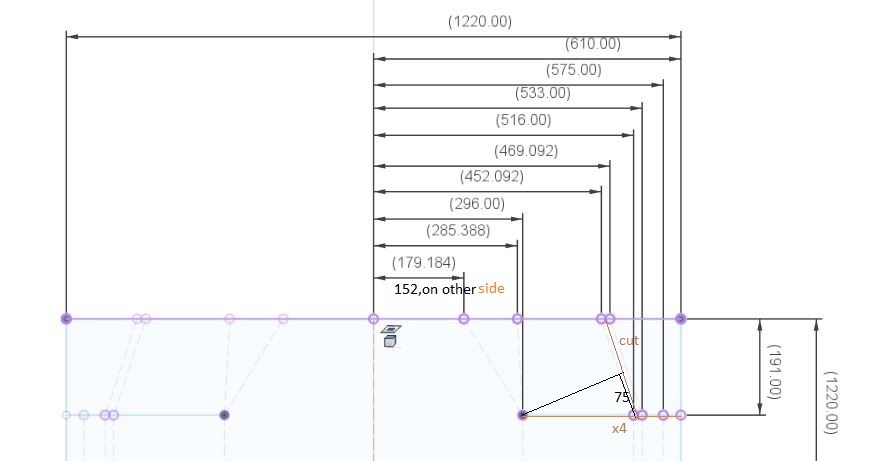
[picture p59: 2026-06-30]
Drawings/seat_v2.3_tested.jpg

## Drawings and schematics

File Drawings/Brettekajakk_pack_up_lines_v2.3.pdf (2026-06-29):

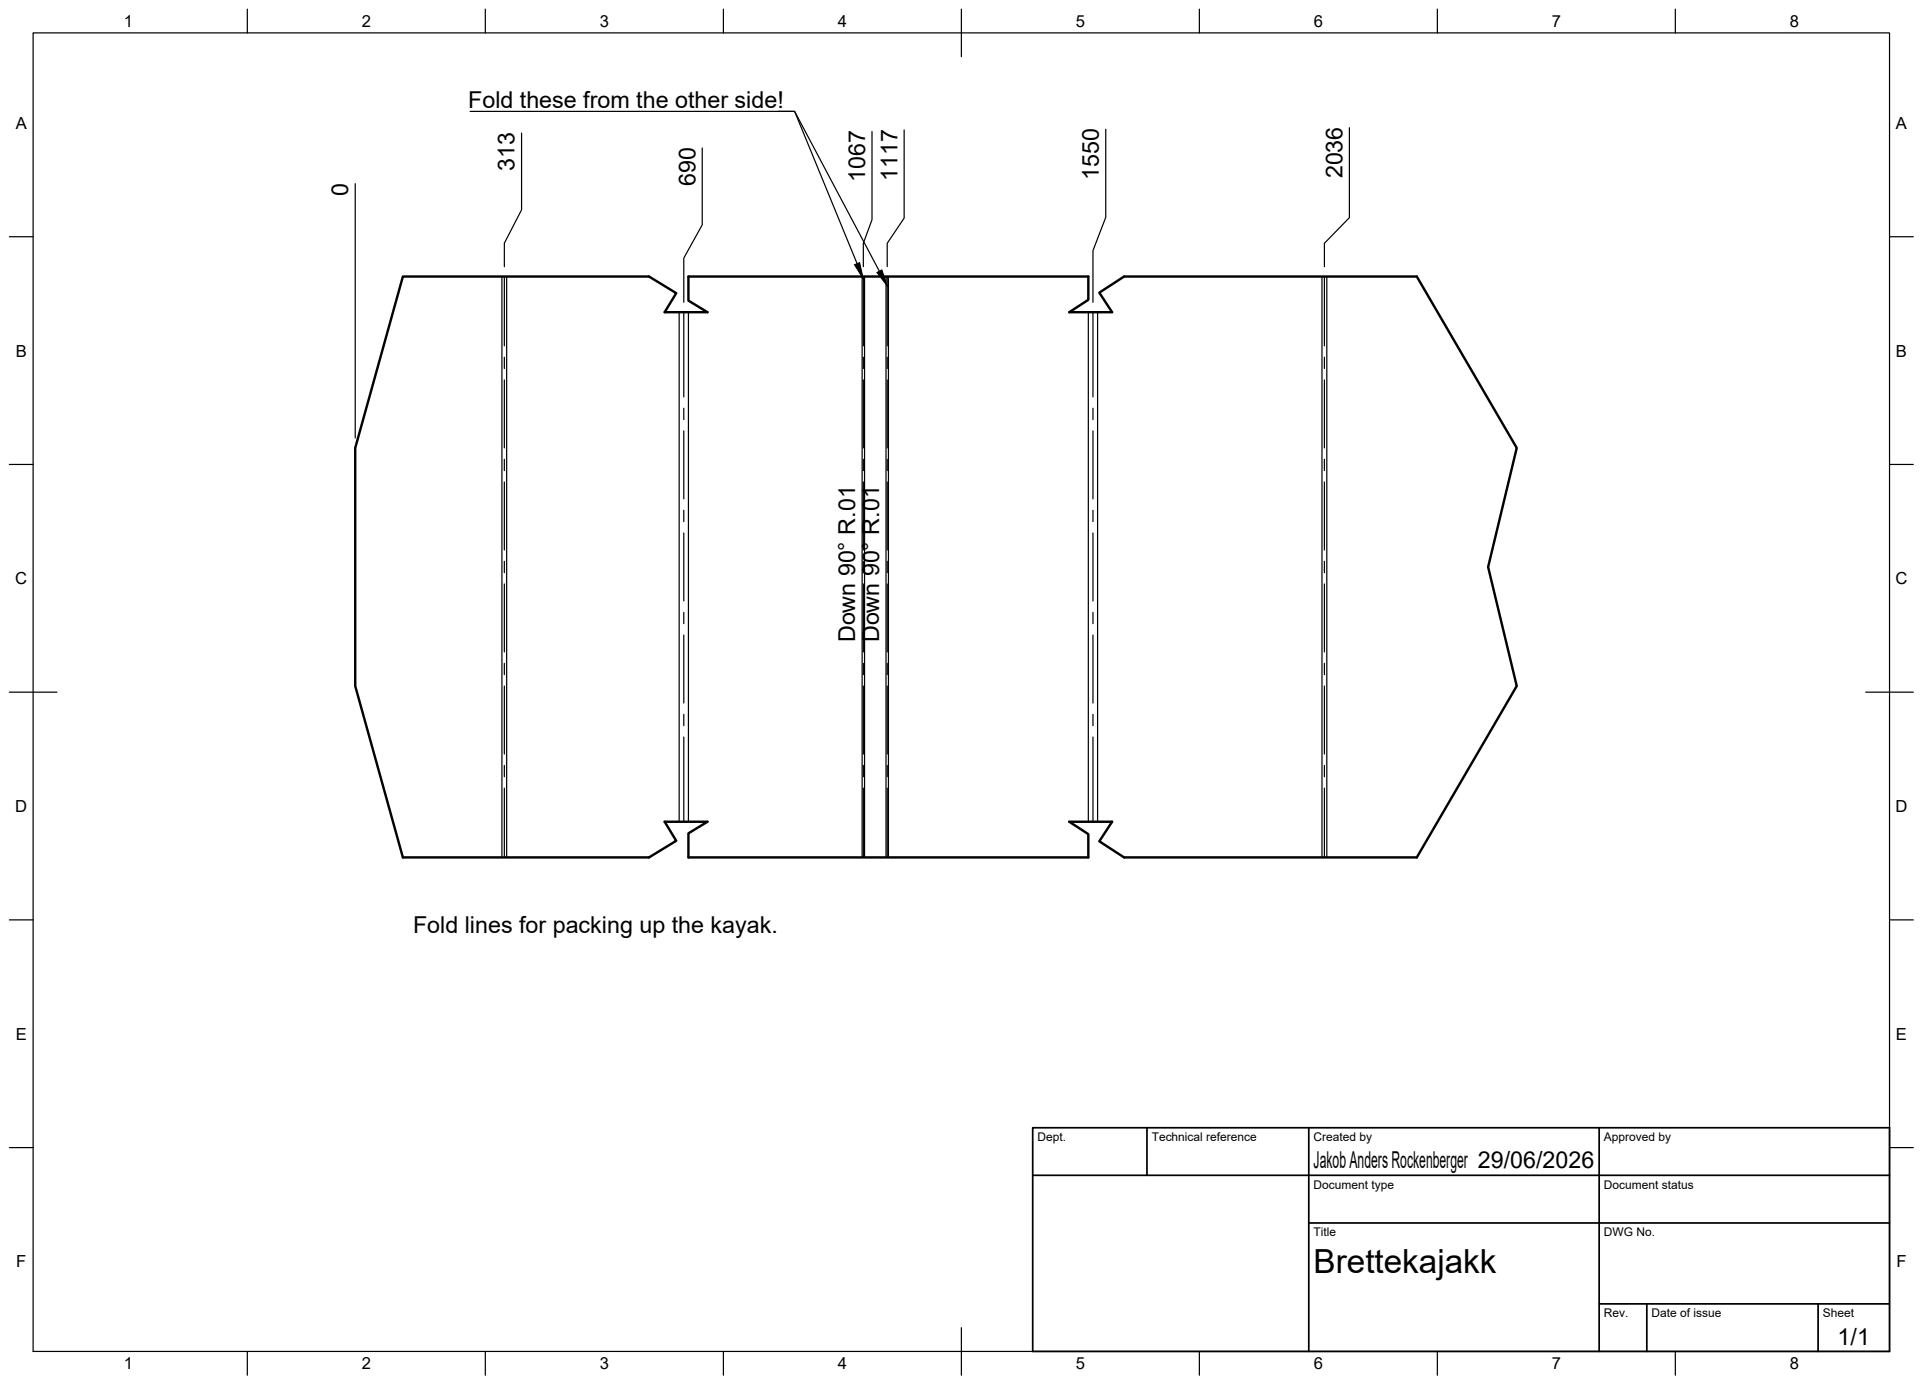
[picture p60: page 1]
Title; DWG No.; Rev.; Date of issue; Sheet; Fold lines for packing up the kayak.; Down 90° R.01; Fold these from the other side!

Dept. | Technical reference | Created by Jakob Anders Rockenberger 29/06/2026 | Approved by

Document type | Document status

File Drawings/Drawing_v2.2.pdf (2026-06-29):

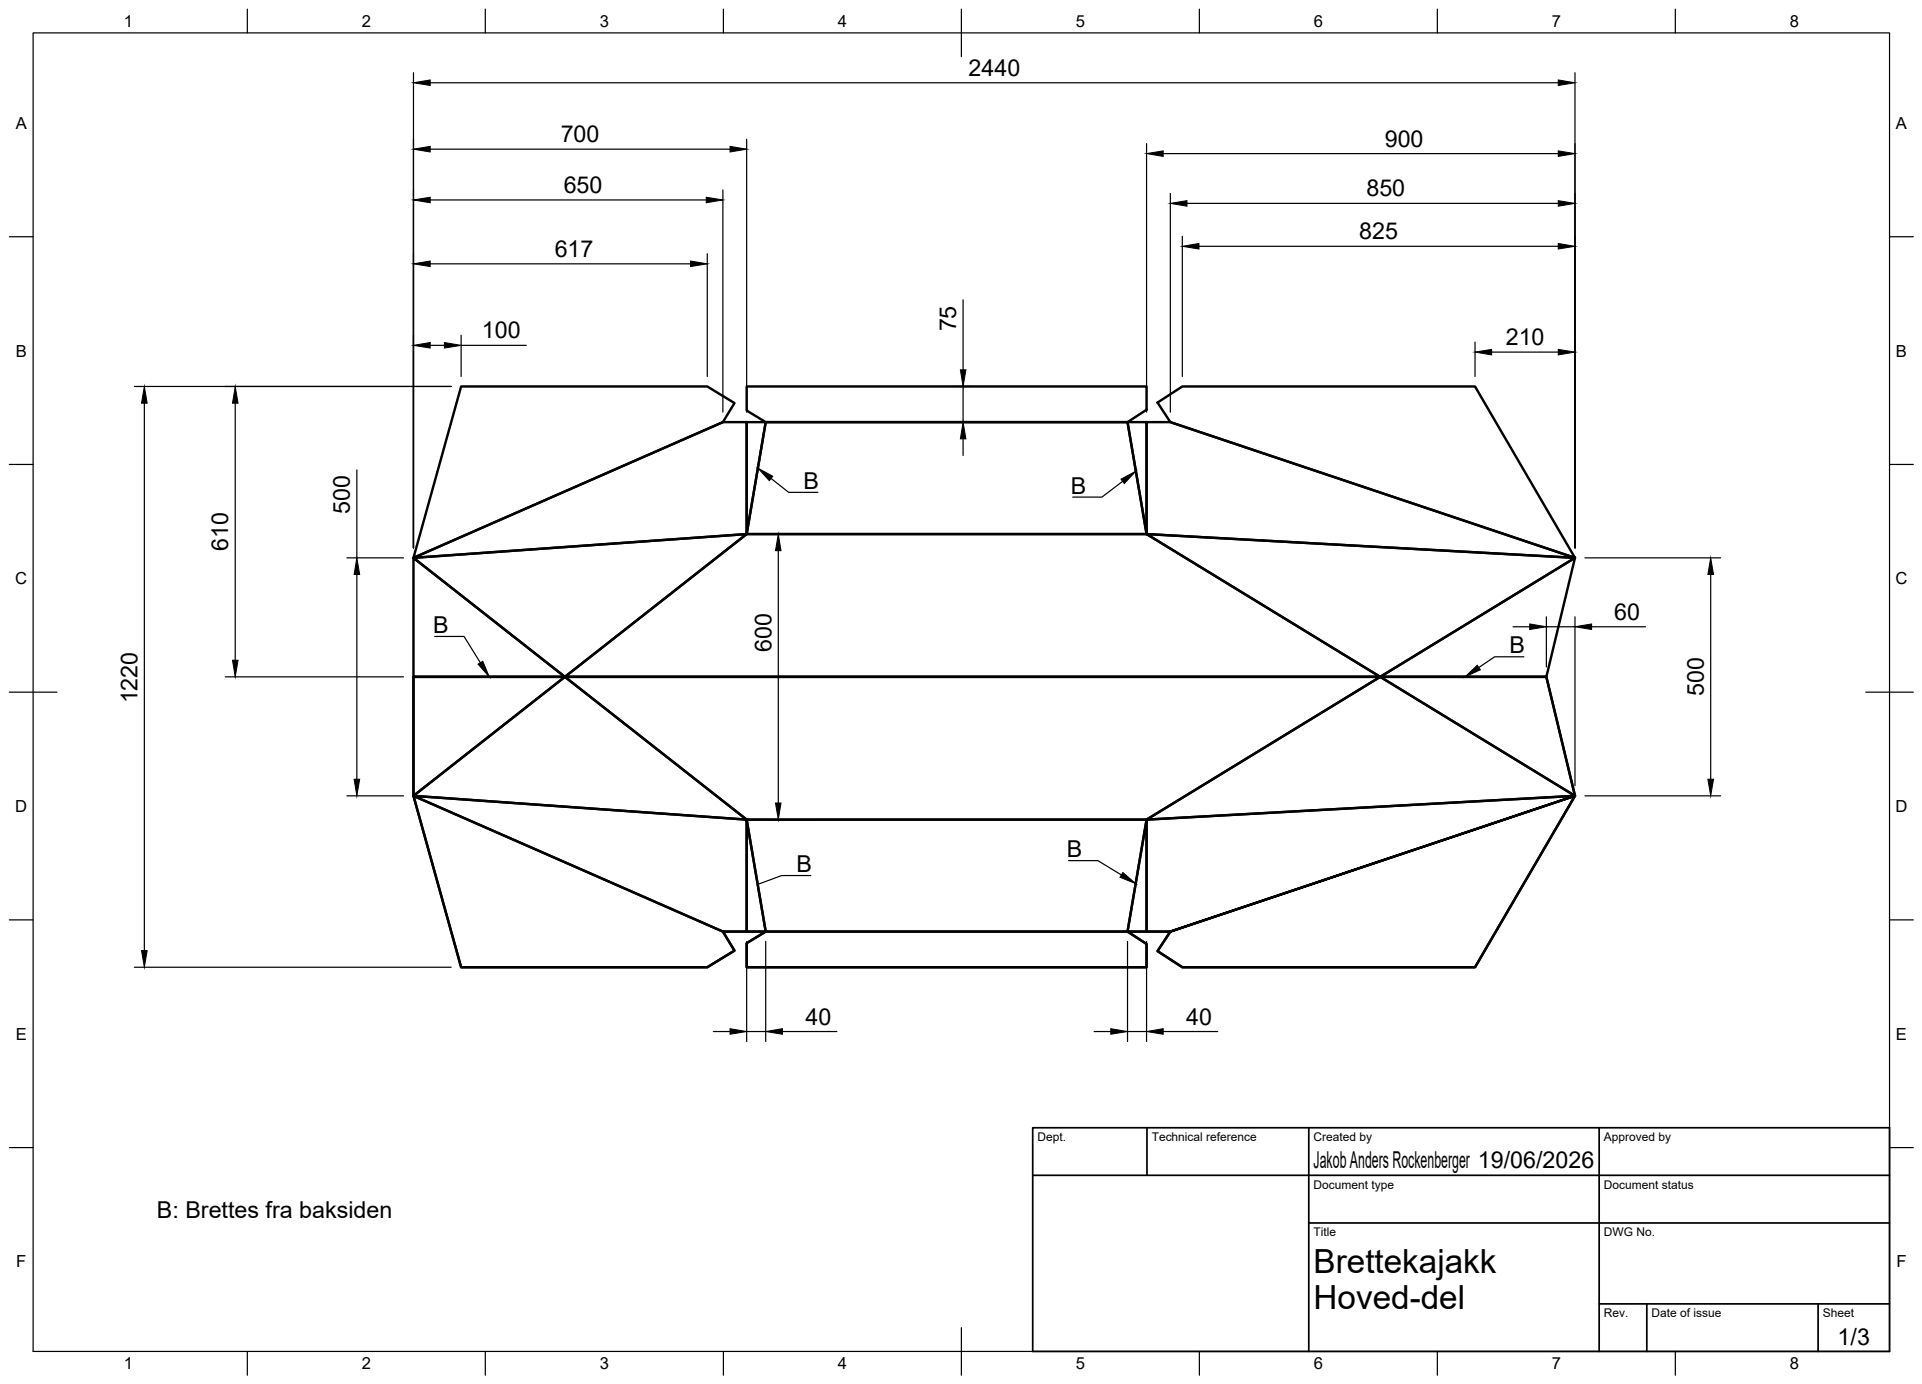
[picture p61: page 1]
Title; DWG No.; Rev.; Date of issue; Sheet

B: Brettes fra baksiden 610

Dept. | Technical reference | Created by Jakob Anders Rockenberger 19/06/2026 | Approved by

Document type | Document status

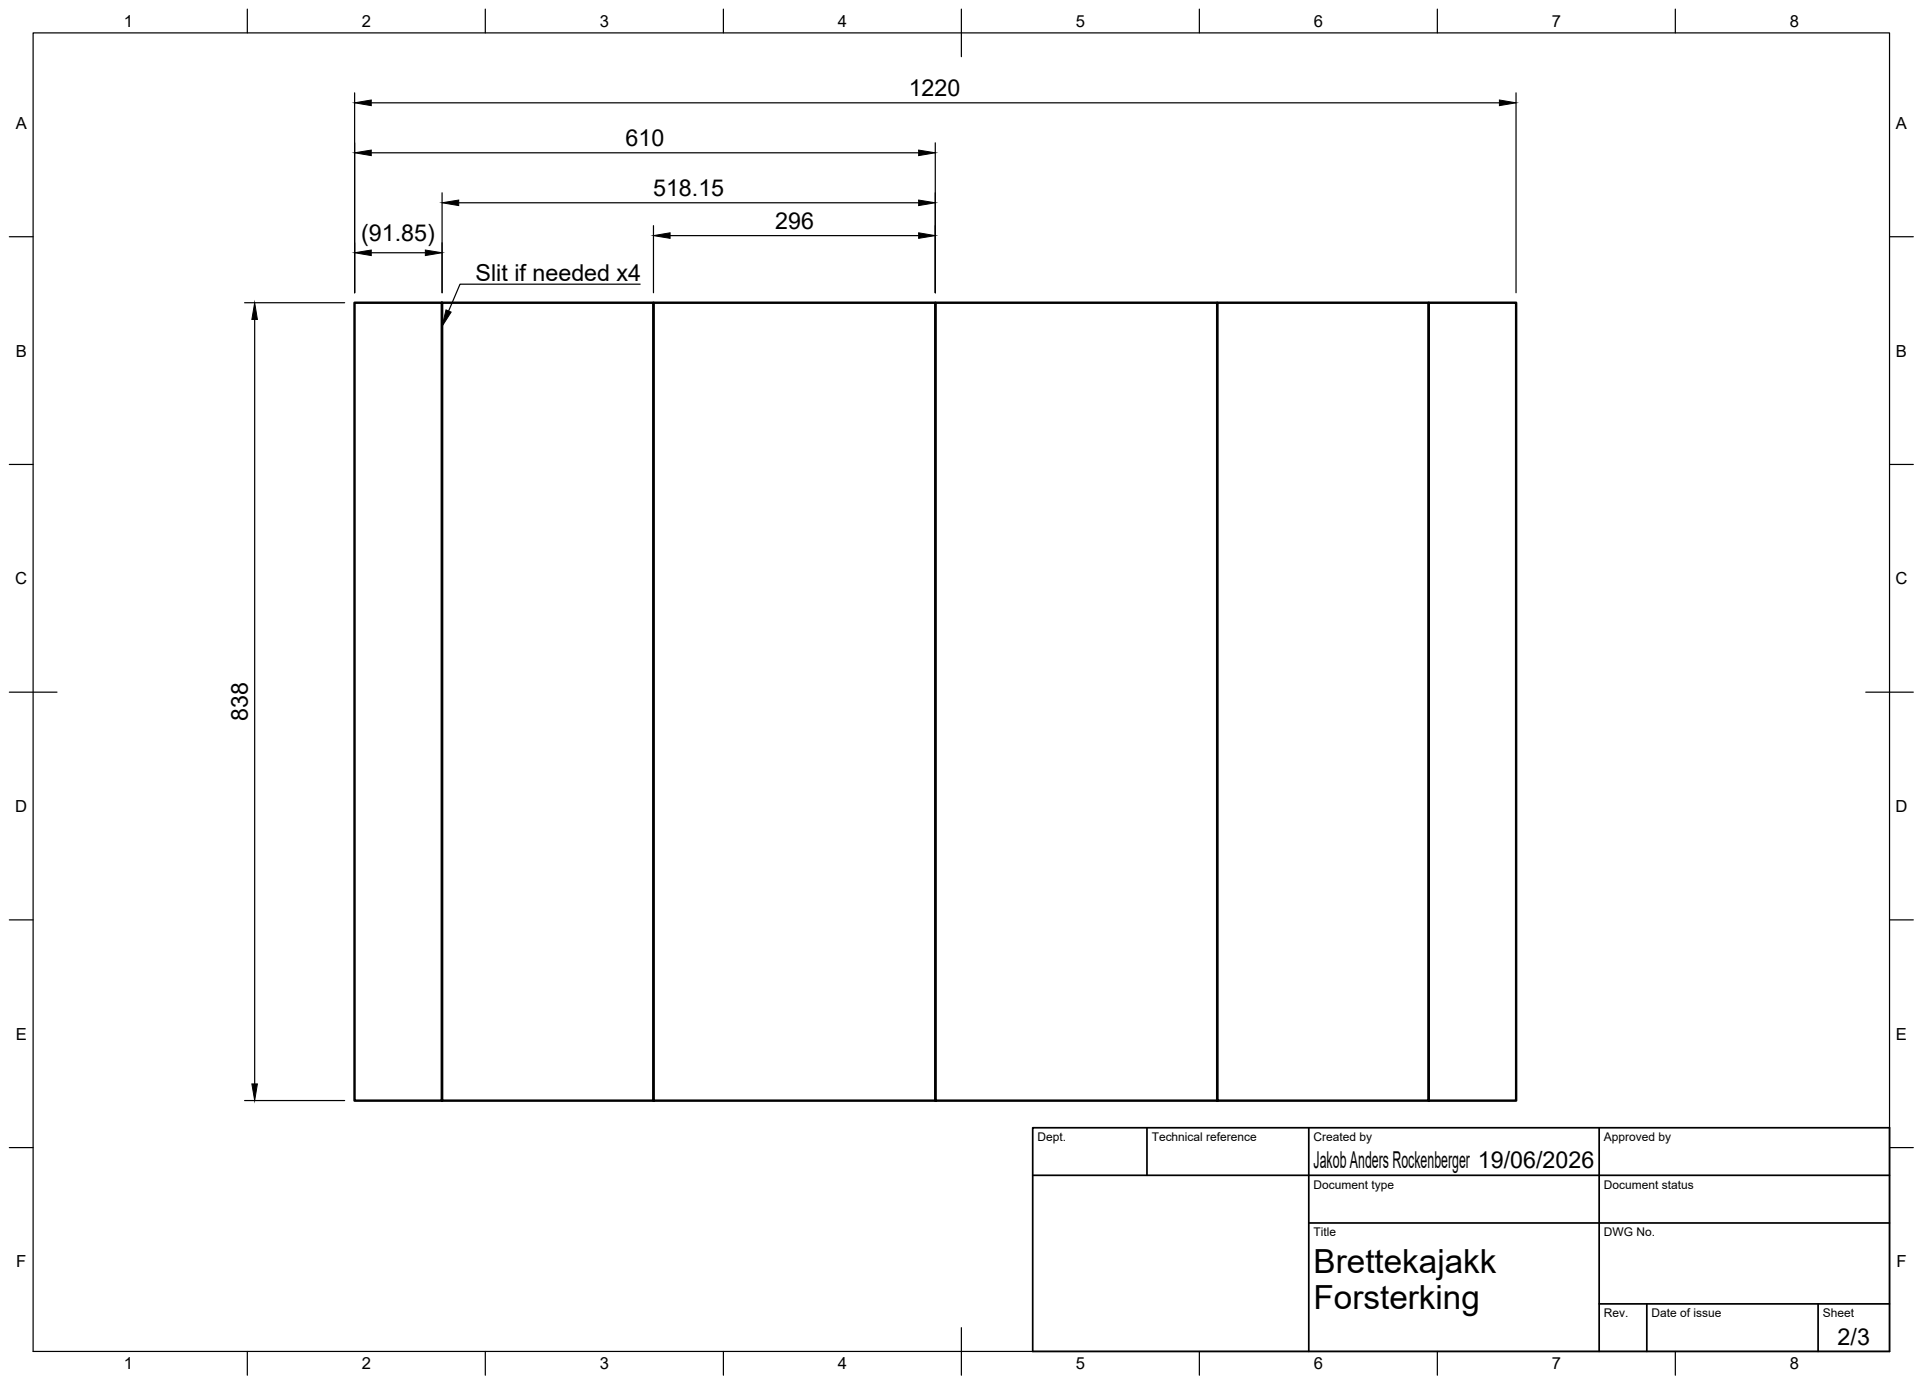
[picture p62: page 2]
Title; DWG No.

Slit if needed x4

Dept. | Technical reference | Created by Jakob Anders Rockenberger 19/06/2026 | Approved by

Document type | Document status

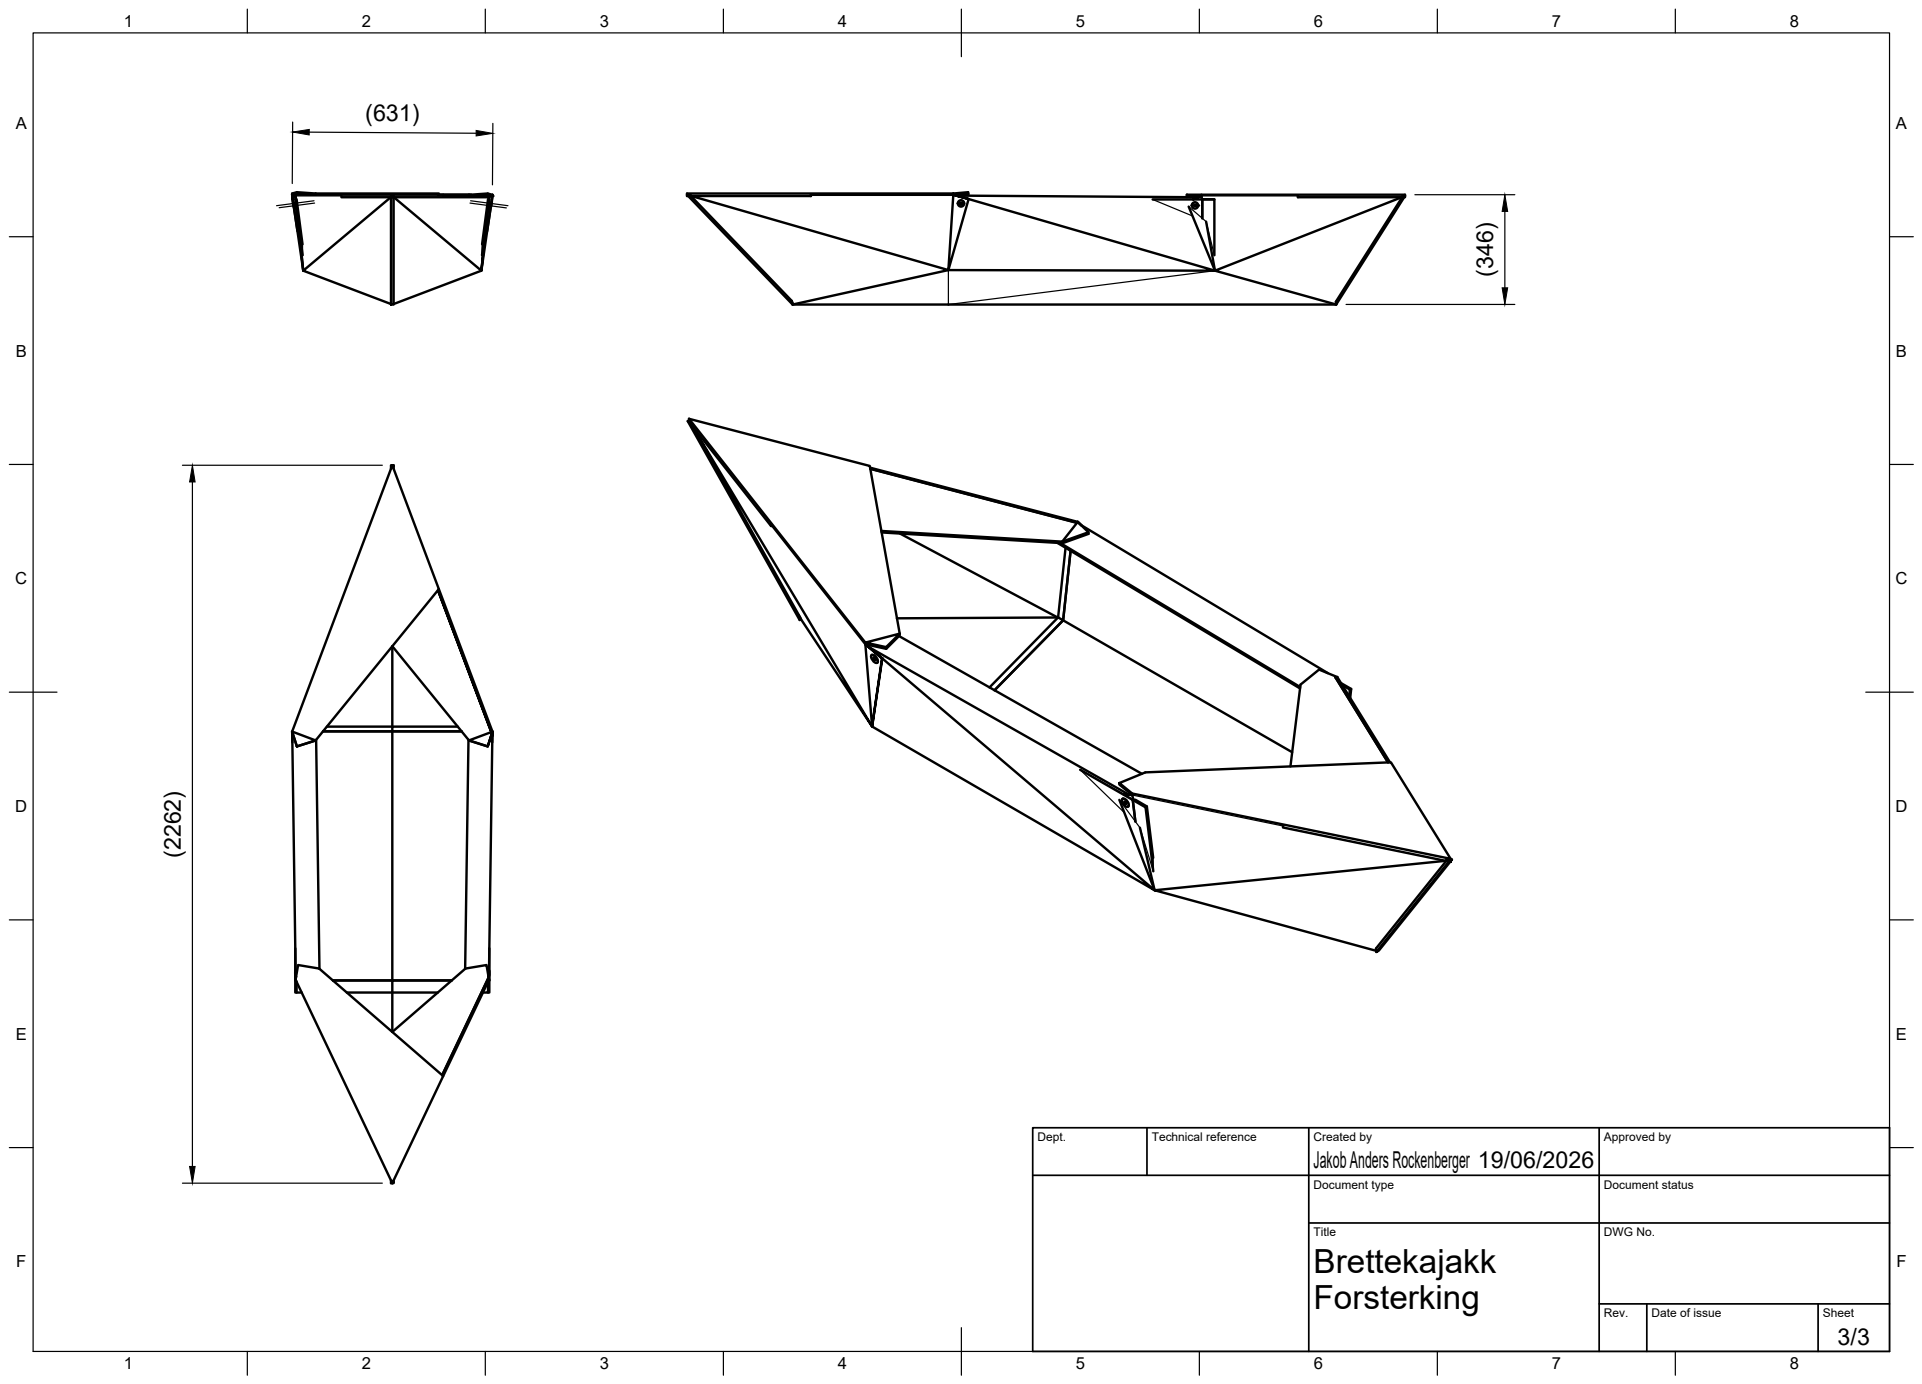
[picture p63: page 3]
Title; DWG No.

Jakob Anders Rockenberger (2262)

Dept. | Technical reference | Created by 19/06/2026 | Approved by

Document type | Document status

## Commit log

2026-06-29 Moved to new repo name
    [10pcs-lock-washers.3mf, Brettekayak_JR_v1.1.dxf, Creasing toool - v1.3dm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]
2026-06-29 Main upload new version
    [Brettekayak_JR_v2.2.dxf, DXF_Seat_reinforce_JR_v2.2.dxf, Seat_v2.3_DXF.dxf]
2026-06-29 Massive update
    [Brettekayak_JR_v2.3.dxf]
2026-07-01 Added updated print files for M6
    [1pcs-Lock-washers-folding-kayak-M6-Screw-holder.3mf, 28pcs-Lock-washers-folding-kayak-M6-Screw-holder.3mf]
2026-09-29 Added fusion add inns
    [#Brettekayak_JR_v2.3.dxf, TestData.csv]
2026-09-30 Righting arm analysis and comparision
    [Simple_pattern_v3.dxf, TestData.csv, TestData_v3_comp.csv]
2026-09-30 v3_drawing_dxf and pic
    [#Simple_pattern_v3_both_sides.dxf, Simple_pattern_v3_both_sides.dxf]
2026-10-01 Betterv3 drawings
    [Simple_pattern_v3.dxf, Simple_pattern_v3_both_sides.dxf, Simple_pattern_v3_top_lines.dxf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]
2026-10-07 Added adapter
    [Adapter.stl]
2026-10-09 Tidy and update log and DIY instructions
    [CreasingToolv1.3dm]
2026-10-09 2.4 Dxf for autocrease
    [#Brettekayak_JR_v2.3.dxf, 24.csv, RightingArmSweep_cleaned_plotted.xlsx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]
2026-10-09 Todo autocreaseday
    [dxf-main_v2.4_railing.dxf]
2026-10-15 prep 2.4 for paper print
2026-10-15 paper kayak for print 2.4
